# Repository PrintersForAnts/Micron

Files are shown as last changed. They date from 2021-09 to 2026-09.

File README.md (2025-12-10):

## Micron R1
Rendering of a Micron build

# [Printed Part Configurator](https://micron.wizards-enclave.net/) 
<p align="center">
  <a aria-label="Stars" href="https://github.com/PrintersForAnts/Micron/stargazers">
    </a> &nbsp;
  <a aria-label="License" href="https://github.com/PrintersForAnts/Micron/blob/master/LICENSE">
    </a> &nbsp;
  <a aria-label="Commits" href="">
    </a> &nbsp;
  <a aria-label="Discord" href="">

</p>
    
[Discord](https://discord.gg/doomcube)

[The official Micron BOM is here.](https://docs.google.com/spreadsheets/d/1caKSc-EukVpRgN67_by_hdzVPlExSRQ66j3OXlEmcCU)

If you want to purchase full kits there are 3 available (Kits are slowly updating to R1 hardware just make sure to double check the included hardware in your kit and if you have any questions reach out in the discord) 

## LDO Motors Kit 
### US Vendors
[Fabreeko](https://www.fabreeko.com/products/ldo-micron-3d-printer-kit-180mm-3d-printer-kit-with-honeybadger-upgrades)

[KB3D](https://kb-3d.com/store/shop-full-build-kits/6567-ldo-micron-r1-3d-printer-build-kit-by-hartk-6975415159954.html)

[West3d](https://west3d.com/products/ldo-micron-3d-printer-kit-micron-plus-180?_pos=1&_sid=03fbc1c81&_ss=r)

### Non US Vendors

[onetwo3d](https://www.onetwo3d.co.uk/product/ldo-micron-r1-diy-kit/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)

[Zen3d](https://shop.zen3d.eu/ldo-micronplus-r1-kit-black)

## Formbot 3d Kit 
<a href="https://www.formbot3d.com/products/voron-micron-r1-180mm-high-quality-corexy-3d-printer-kit-latest-version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" rel="nofollow">Formbot Micron+ (180x180) Kit (Affiliate Link)</a>

<a href="https://s.click.aliexpress.com/e/_DBn6Ptd" rel="sponsored">Funssor Micron (120x120) Kit (Affiliate Link)</a>

<a href="https://s.click.aliexpress.com/e/_DDDUFkF" rel="nofollow">Formbot Micron+ (180x180) Kit (Aliexpress Affiliate Link)</a>

## [R1 Change Log](https://github.com/PrintersForAnts/Micron/blob/main/R1_changeLog.md)

<details> 
   <summary>
    120x120 build
    </summary>

## Frame Extrusions
Misumi Part #  |Qty | Notes
 ----|----|----|
HFS3-1515-300 |4 | Blind holes need to be drilled
HFS3-1515-220 |10| Ends need to be tapped (M3)
HFS3-1515-205 |2 |
HFS3-1515-190 |1 |
HFS3-1515-120 |1 |

## Linear Rails
Part  | Qty | Length | Notes
-----|----|----|----|
MGN7H | 6 | 160mm | will work with V0 150mm rails if wanted, but 160mm will work as well and is recommended  
MGN9C OR MGN9H | 1 | 160mm | will work V0 150mm rails but 160 will work as well and is recommended 
</details>

<details>
    <summary>
    180x180 build
    </summary>
    
## Frame Extrusions
Misumi Part #  |Qty | Notes
 ----|----|----|
HFS3-1515-350 |4 | Blind holes need to be drilled
HFS3-1515-280 |10| Ends need to be tapped (M3)
HFS3-1515-265 |2 |
HFS3-1515-250 |1 |
HFS3-1515-180 |1 |

## Linear Rails
Part  | Qty | Length
-----|-----|-----|
MGN7H | 6 | 220mm
MGN9C OR MGN9H | 1 | 220mm 
</details>

## No Drop Nuts
There are 2 versions of this mod, 1 from [Zruncho](https://github.com/VoronDesign/VoronUsers/tree/master/printer_mods/zruncho/V0_No_Drop_Nuts) and the other from a user named [Zen3D](https://github.com/VoronDesign/VoronUsers/tree/master/printer_mods/Zen3D/V0_1515_T-nut/). Both of them have their uses. I prefer to use the Zen3D kind just for the fact that the screw can go all the way through the printed part. Zrunchos do have a much nicer fitment into the extrusions but they also dont allow the screw to go all the way through.

## Thank you
Thanks to the following people on Discord who have helped make this printer what it is today. 

- [@KyleGB](https://github.com/Jadecky) - too many additions to name them all
- @TheWarolf#1247
- @L.e.o.p.a.r.d#0990
- @deepfriedheroin#5006
- @JosAr#0517
- @sentein#3903
- @madcat#7838
- @Kyrios#5486
- @faithblinded#1491
- @zruncho#1790
- @Finn#2449
- @clee#1337
- @slidr#4412
- @gfunnymoney#3748
- Jason from LDO
- Voron Dev Team
- all the R1 beta testers
  
[You can support the Micron project on Patreon](https://www.patreon.com/user?u=27661824&fan_landing=true).

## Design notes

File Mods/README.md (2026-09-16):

# Mods

Printer mods for MICRON
Remember to update this README when uploading new mod!

## Table structure

Update the following table with the information about your mod:
- Your name
- A link to your sub-folder
- A short description of your mod

like so:
`
| Creator | [Mod title](link) | Description |`

---

| Creator | Mod title | Description |
| --- | --- | --- |
|Asica10|[Z_idler](https://github.com/Asica10/Micron/tree/main/Mods/Asica10/Z_idler) | Z idler carriage adjusted for 15mm toothed idler / Z idler body with wires cutout.
||[Crazy_Ivan_double_shear](https://github.com/Asica10/Micron/tree/main/Mods/Asica10/Crazy_Ivan_double_shear) | Crazy Ivan for double shear stepper shaft.
|LordKillZone|[3010_Side_Bedfans](https://github.com/printersforants/Micron/tree/main/Mods/LordkillZone/Side_3010_bedfans) | Bedfans mount for 3010 blower. Side  mount under bed
|BlueSandBox|[Nema_17_Z_Motor_Mount](https://github.com/printersforants/Micron/tree/main/Mods/BlueSandBox/Nema_17_Z_Motor_Mount) | Replaces the Nema14s with Nema17s
|clee|[Micron+](https://github.com/printersforants/Micron/tree/main/Mods/clee) | Micron+
|Finn2708|[Dual_MGN7_Toolhead_Carriage](https://github.com/printersforants/Micron/tree/main/Mods/Finn2708/Dual_MGN7_Toolhead_Carriage) | Dual MGN7H Toolhead Carriage 
||[Zerofilter_mounting_bracket](https://github.com/printersforants/Micron/tree/main/Mods/Finn2708/Zerofilter_mounting_bracket) | Mounting bracket for Zerofilter 
||[AB_Motor_Microfit_Connector](https://github.com/printersforants/Micron/tree/main/Mods/Finn2708/AB_Motor_Microfit_Connector) | AB Motor Microfit Connector
|Hartk|[Spinner](https://github.com/printersforants/Micron/tree/main/Mods/hartk1213/Spinner) | Spinner for Micron A/B drives.
||[LRS-150-Stacked](https://github.com/printersforants/Micron/tree/main/Mods/hartk1213/LRS-150-Stacked) | Stacked electronics for LRS-150 PSU and octopus.
||[bed_wagos](https://github.com/printersforants/Micron/tree/main/Mods/hartk1213/bed_wagos) | Bed wagos
||[plate_holder_panel_clips](https://github.com/printersforants/Micron/tree/main/Mods/hartk1213/Panel_Clip_Plate_Holder) | Plate Holder Panel Clips
||[Belt Chain](https://github.com/printersforants/Micron/tree/main/Mods/hartk1213/belt_chain) | Belt Chain 
|L.e.o.p.a.r.d|[Clips](https://github.com/printersforants/Micron/tree/main/Mods/L.e.o.p.a.r.d/Clips) | This mod contains various clips for mounting things onto 1515 and 2020 extrusion.
||[EasierZDrives](https://github.com/printersforants/Micron/tree/main/Mods/L.e.o.p.a.r.d/EasierZDrives) |  Alternate Z Drives
||[FrenzyCarriage](https://github.com/printersforants/Micron/tree/main/Mods/L.e.o.p.a.r.d/FrenzyCarriage) | Alternate Carriage for Micron and other 1515 MGN9C machines.
||[Firmware](https://github.com/printersforants/Micron/tree/main/Mods/L.e.o.p.a.r.d/Firmware) | Leopard's labeled wiring photos/examples, and mainsail config (with auto-z-calibration and sensorless X/Y)
||[HeatsetZTensioner](https://github.com/printersforants/Micron/tree/main/Mods/L.e.o.p.a.r.d/HeatsetZTensioner) | Alternate Z Idler that can utilize a heatset
||[KeyedSkirts](https://github.com/printersforants/Micron/tree/main/Mods/L.e.o.p.a.r.d/KeyedSkirts) | Keyed Skirts
||[KineKlicky](https://github.com/printersforants/Micron/tree/main/Mods/L.e.o.p.a.r.d/KineKlicky) | Kinetic-mount Klicky, useful if you're having some issues with your klicky
||[M3MicronFeetAdapter](https://github.com/printersforants/Micron/tree/main/Mods/L.e.o.p.a.r.d/M3MicronFeetAdapter) | This mod contains a hex-nut-adapter that allows you to use the standard z-drive baseplate, but install something with an M3 screw (e.g. V0 feet).
||[PiCameraMountFor1515](https://github.com/printersforants/Micron/tree/main/Mods/L.e.o.p.a.r.d/PiCameraMountFor1515) | This mod contains a mount compatible with a standard Pi camera. It articulates in various ways, and is mountable in various directions.
||[RibbitToolhead](https://github.com/printersforants/Micron/tree/main/Mods/L.e.o.p.a.r.d/RibbitToolhead) | An alternate toolhead which puts the part cooling fans on external "legs", which might improve cooling and possibly give more 'x' clearance for your gantry.
|Reiten966|[Micron Handles](https://github.com/printersforants/Micron/tree/main/Mods/Reiten966/Micron_Handles) | Handles for Micron
|TheWarolf|[Neopixel_Mount](https://github.com/printersforants/Micron/tree/main/Mods/TheWarolf/UglyNeopixelMount) | Simple Neopixel strip mount for 1515 extrusions
||[Anti_Rotation_Corners](https://github.com/printersforants/Micron/tree/main/Mods/TheWarolf/AntiRotationCorners) | Modified bed support extrusion corner pieces 
| xbst_ | [2-Piece Skirt Display Mount](./xbst_/2_Piece_Skirt_Display_Mount) | A simple insert for the middle hex of the front skirts to mount a display using the stock mount. |
|| [Drag Chain Chamber Thermistor](./xbst_/Dragchain_Thermistor) | A thermistor mount on the drag chain guide (for chamber temperature monitoring). |
|| [LED Mount](./xbst_/LED_Mount) | Top LED mount for PCB LED strips with M3 holes. |
|| [Vertical Pi](./xbst_/Vertical_Pi) | Relocates the Pi, eliminating the risk of the bottom panel shorting the pins, and makes accessing GPIO easier. Also adds a second latch for the hinge. |
|| [Simpler Electronics](./xbst_/Simpler_Electronics) | No-hinge electronics mounts for the UHP PSU, BTT Octopus & Pi. Pi Mounts to a skirt, UHP and octopus are stacked. |
|Maker Technologies|[RRF Config](https://github.com/printersforants/Micron/tree/main/Mods/Maker%20Technologies/RRF%20Firmware) | Rerprap Firmware Config for use with Duet Web Control
|gfunnymoney|[MicronPlusDinRailMount](https://github.com/PrintersForAnts/Micron/tree/main/Mods/gfunnymoney/MicronPlusDinRailMount) | Micron+ DIN rail mount
||[MicronSideSkirtKeystonePort](https://github.com/PrintersForAnts/Micron/tree/main/Mods/gfunnymoney/MicronSideSkirtKeystonePort) | Keystone side skirt Micron 120.
|CoookieTM|[OwO Chef Bolt](https://github.com/PrintersForAnts/Micron/tree/main/Mods/CoookieTM/OwO%20chef%20bolt) | Easier to print Z endstop housing
||[PIP Inner Access Z Chain](https://github.com/PrintersForAnts/Micron/tree/main/Mods/CoookieTM/PIP%20inner%20access%20z%20chain) | Print in Place Z Chain
||[Aesthetic No-Panel Clips](https://github.com/PrintersForAnts/Micron/tree/main/Mods/CoookieTM/aesthetic%20panel%20clips) | Aesthetic clips for use with NO panels
||[B Motor Ziptie Mount](https://github.com/PrintersForAnts/Micron/tree/main/Mods/CoookieTM/b%20motor%20tail%20mount) | Add-on to provide a ziptie mounting point
||[Beefed Up Side Mount Handle](https://github.com/PrintersForAnts/Micron/tree/main/Mods/CoookieTM/beefy%20handle) | Handle that is NOT compatible with panels
||[Z Motor Spinner Flags](https://github.com/PrintersForAnts/Micron/tree/main/Mods/CoookieTM/fixed%20spinner) | Rock how gangster your micron is
||[Larger Z Belt Covers](https://github.com/PrintersForAnts/Micron/tree/main/Mods/CoookieTM/larger%20z%20belt%20covers) | Covers gaps in the bottom panel
||[Spool Mount with Rollers](https://github.com/PrintersForAnts/Micron/tree/main/Mods/CoookieTM/rolling%20spool%20mount) | Reduces friction for spools
|risqy|[Micron+ 4010 Bed Fans](https://github.com/printersforants/Micron/tree/main/Mods/risqy/Micron-Plus-Bed-Fans) | Micron+ Bed Fan Mount for 2x 4010 Blower
|Shix|[MicronPlus mini12864 front skirt Mount](https://github.com/PrintersForAnts/Micron/tree/main/Mods/Shix/MicronPlus%20mini12864%20front%20skirt%20mount) | Mounting Options for the mini12864 for the front skirt of the Micron+
|G|[1515 Bed Angle Bracket (Notched)](./G/1515%20Bed%20Angle%20Bracket%20Notched) | Notched bed angle bracket for R1 Micron Filter |
||[1515 BTT SFS Mount](./G/1515%20BTT%20SFS%20Mount) | BTT Smart Filament Sensor Mount based on the bowden tube holder |
||[1515 Daygreen 5VDC Voltage Regulator Mount](./G/1515%20Daygreen%205VDC%20Regulator%20Mount) | Low profile for Micron bay mounting of the Daygreen 5VDC Voltage Regulator |
||[Bowden Tube Holder (Extended)](./G/Bowden%20Tube%20Holder%20Extended) | Extended Micron bowden tube holder to fit the R1 top panel with 3mm foam |
||[More WAGO Mounts](./G/More%20WAGO%20Mounts) | Additional wago mounts based on the micron 1515 mount for two five-port and two three-port configurations |
||[Zip Tie and PCB DIN Clip](./G/Zip%20Tie%20and%20PCB%20DIN%20Clip) | Modified PCB DIN Clip to add zip tie holes |
---

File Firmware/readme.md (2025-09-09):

# Micron Firmware Config

run this script in your terminal to download the basic Micron cfg, 

```
cd ~/printer_data/config && curl -s https://api.github.com/repos/PrintersForAnts/Micron/contents/Firmware/printer_data/config | grep download_url | cut -d '"' -f 4 | xargs -n1 curl -sOL
cd ~/printer_data/gcodes && curl -s https://api.github.com/repos/PrintersForAnts/Micron/contents/Firmware/printer_data/gcodes | grep download_url | cut -d '"' -f 4 | xargs -n1 curl -sOL
```

make sure to go through the entire cfg and uncomment the sections required 

* Build Size (120 or 180) 
* MCU
* Toolhead MCU
* Probe

This will download he default config as well as a sample gcode for printing a test cube

to initiate the test cube print, run the macro 

`PRINT_TEST_CUBE` 
then your webui will prompt you to choose which filament type you are using for the test print 


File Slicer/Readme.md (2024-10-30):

Slicer Profiles, Bed Models, Bed textures can be found here

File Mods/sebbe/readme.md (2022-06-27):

<h1> Hardware for all my voron projects utilize standard m3 heatset inserts & various lengths of m3 screws </h1>

Feel free to mod / change the parts as you like :-)

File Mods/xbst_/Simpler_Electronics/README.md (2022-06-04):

# Simpler Electronics
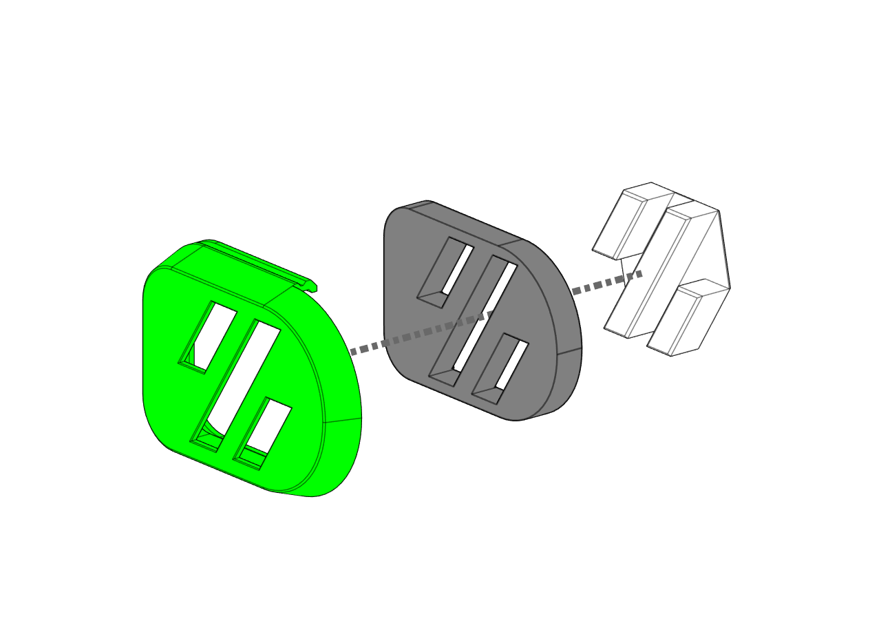
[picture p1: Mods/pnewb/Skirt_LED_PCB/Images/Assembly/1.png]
Example

<br>
I wasn't a fan of the hinged electronics (below), so I created this. Less files to print, less screws and inserts needed, more accessible Pi, and no hinge.
<br>
The PSU is VHB taped or screwed to the deck panel, the Octopus mount is VHB taped on the PSU. Pi mounts to a side skirt.
<br>
There are 2 versions of the Pi skirt, with M2 self-tapper screws or with M2.5 inserts. I like using inserts where possible, and M2.5 is the correct screw size for a Raspberry Pi, so this is what I use. The M2.5 inserts I used can be found on [Aliexpress](https://s.click.aliexpress.com/e/_9gw57l), size M2.5 X D4.2 X L3.6.
<br>

### Why I didn't like the hinge?
1. Wire management was difficult. Managing wires to not go under the PSU was difficult. Wires under the PSU means you con't lock the latch.
2. It was unnecessary. Hinge doesn't make accesing the components easier. The PSU is still screwed under the Octopus, blocking the DC side.
3. Pi mounting location wasn't ideal. You needed to remove screws to access the Pi, and the bottom side was facing the bottom panel, increasing shorting risk (if bottom panel is ACM). I designed [a mod](../Vertical_Pi) to fix this if you still want the hinge.

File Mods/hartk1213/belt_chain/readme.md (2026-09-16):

## Belt Chain
printed alternative for the Z chain that uses a length of gt2 belt down the center of it 




to secure the belt to the chain ends , a short piece of filament is pressed into the printed part between the teeth of the belt


then you can thread each link down onto the belt one at a time 


then secure the other end the same way you did the first end 

this works with stock [Micron 2 hole chain mounts](https://github.com/PrintersForAnts/Micron/tree/main/STLs/Z_Chain/2_hole_chain)

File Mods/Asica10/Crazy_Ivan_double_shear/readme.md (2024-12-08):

# Crazy Ivan with double shear
In Crazy Ivan mod one stepper is mounted upside down. The main advantage of this solution is that you can use a standard stepper with a 22 mm shaft, which is supported by a bearing over the entire thickness of the bearing.
Mod required 2pcs of F695 flanged bearing.

Note: for this mod you need to print 2x B stepper mod from main repo ( A stepper mod is not used).









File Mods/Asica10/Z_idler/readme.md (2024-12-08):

# Z idler carriage adjusted for 15mm toothed idler 
For idler from Mellow 3D.
You can choose between standard version - screw as an axis



or pin_mod version OD3 x 19mm





# Z idler body with wires cutout

For easier wire routing ( e.g LED or camera)







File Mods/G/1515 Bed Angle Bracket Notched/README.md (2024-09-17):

# 1515 Bed Angle Bracket (Notched)

This is a modifed bed angle bracket to allow the use of the Micron R1 filter with the original shorter bed mount extrusions and bracket. 

Mirror the part in the slicer to print the opposite side. 

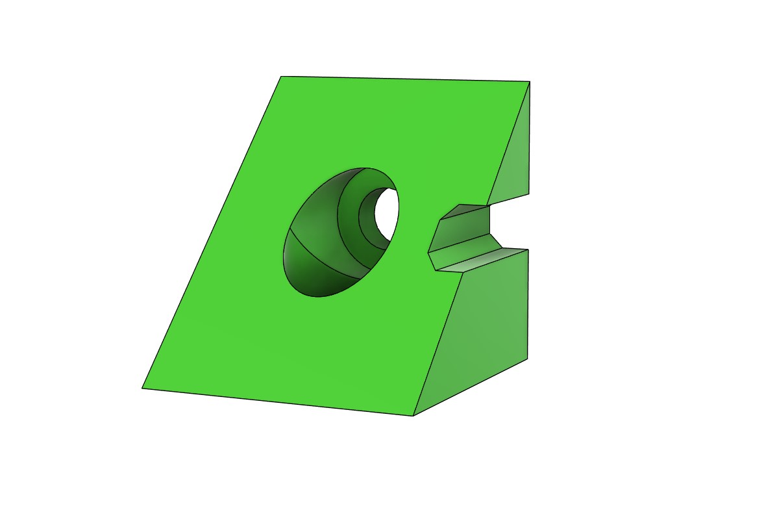
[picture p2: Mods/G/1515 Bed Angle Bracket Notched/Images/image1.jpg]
CAD image


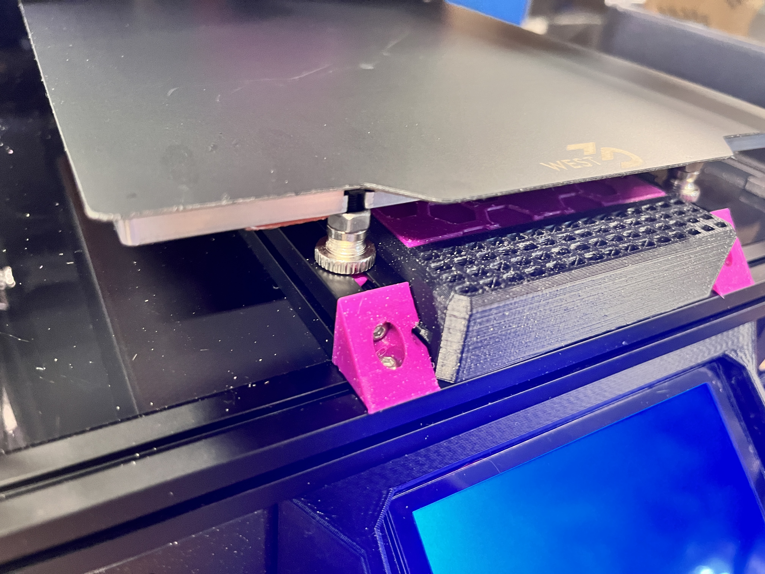
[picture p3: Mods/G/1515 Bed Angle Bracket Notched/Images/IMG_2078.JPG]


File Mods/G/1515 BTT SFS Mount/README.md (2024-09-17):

# 1515 BTT SFS Mount

This is a mount based off of the Micron Bowden Tube Holder and is intended to be used in place of one. Install an M3 heatset insert in the printed bcakplate and replace the SFS backplate with the printed part using using the same screws. The SFS is secured to the bracket with a 20mm long screw. 

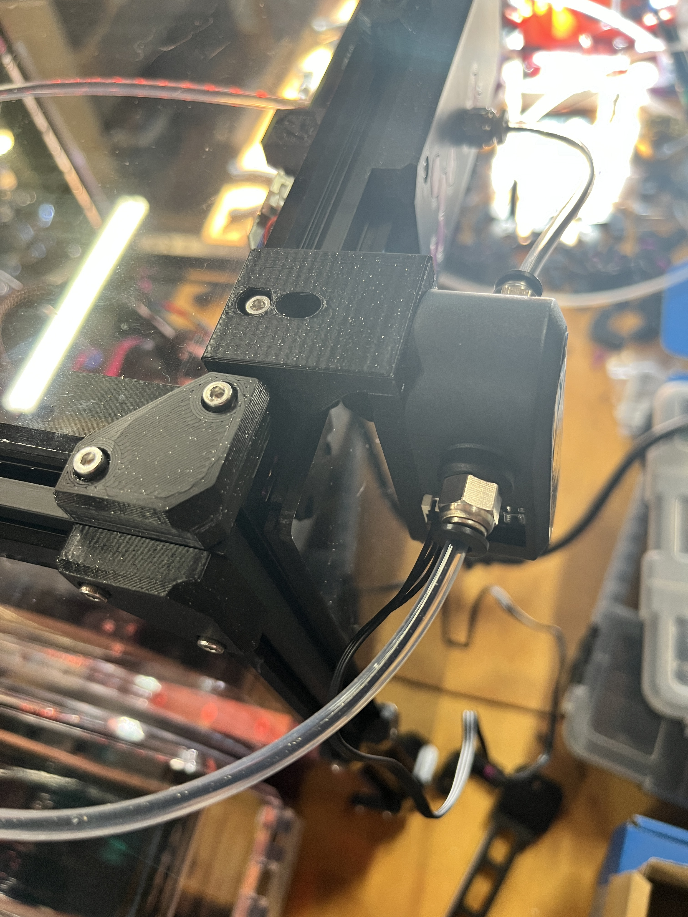
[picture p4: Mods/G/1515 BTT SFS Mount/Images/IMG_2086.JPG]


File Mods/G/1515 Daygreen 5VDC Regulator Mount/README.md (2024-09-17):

# 1515 Daygreen 5VDC Regulator Mount

This is a mount based off of the 1515 WAGO mount to secure a Daygreen 5VDC Voltage Regulator. Four heatset inserts are used in the mount to fasten the regulator. 

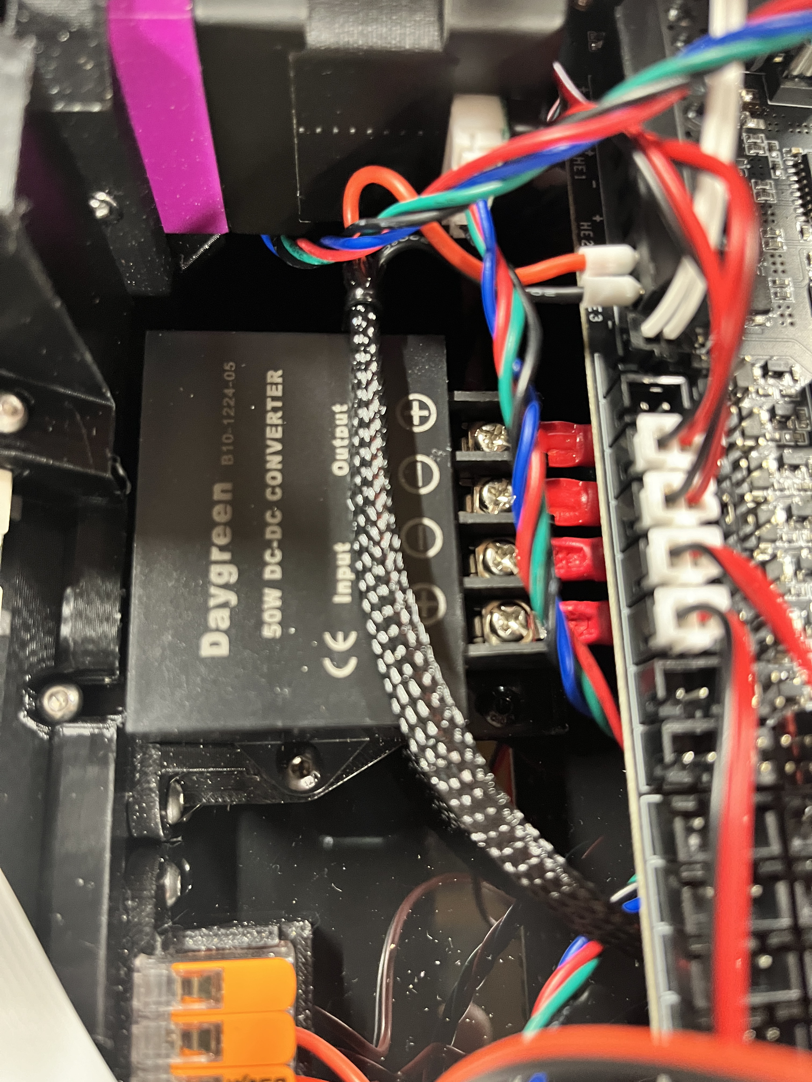
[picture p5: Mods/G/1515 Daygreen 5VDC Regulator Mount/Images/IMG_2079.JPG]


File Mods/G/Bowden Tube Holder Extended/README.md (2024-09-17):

# Bowden Tube Holder Extended

This is a modified Bowden Tube Holder to fit the R1 panels with 3mm foam underneath.

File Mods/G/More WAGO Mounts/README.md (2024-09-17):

# More WAGO Mounts

These are modified from the Micron 1515 WAGO Mount for two three-port and two five-port WAGOs.

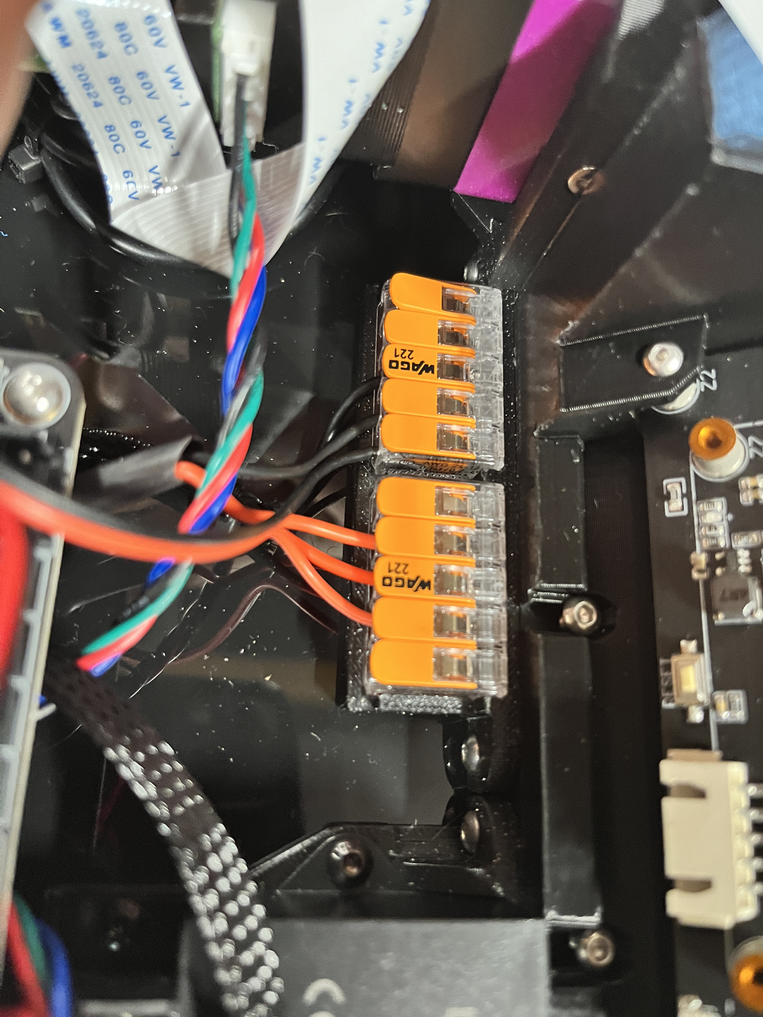
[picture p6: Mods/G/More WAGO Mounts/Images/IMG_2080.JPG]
five-port


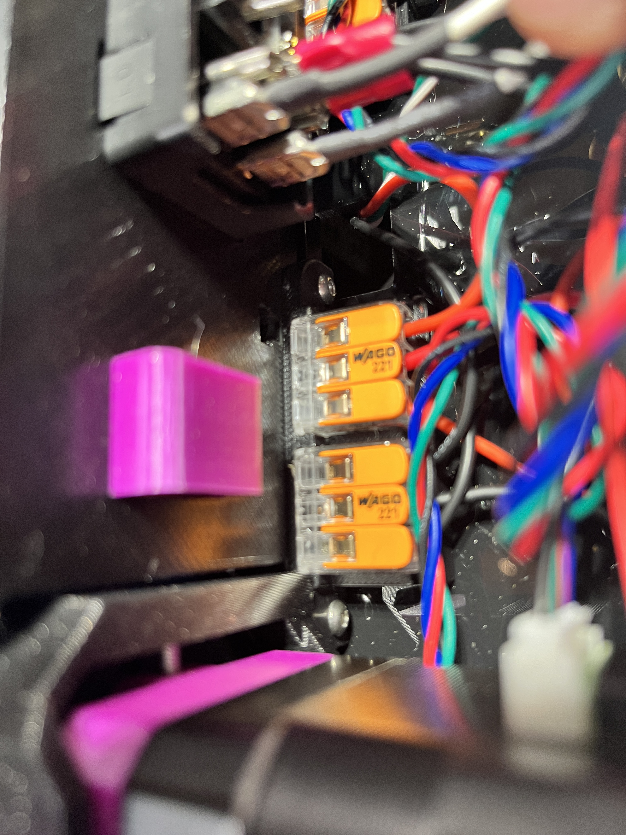
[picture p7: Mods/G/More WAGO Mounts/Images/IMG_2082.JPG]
two-port


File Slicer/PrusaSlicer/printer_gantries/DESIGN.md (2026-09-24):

# Design notes — Micron / Anthead sequential-print geometry

> **Derived with [Claude](https://claude.com/claude-code).** The slice semantics were read out
> of the PrusaSlicer source, the envelope was measured from the toolhead mesh, and both
> verification passes below were run programmatically. Reviewed by a human before submission,
> but treat the numbers as machine-derived and check them against your own hardware.

How the envelope in `micron_anthead_gantry.json` was derived from the toolhead mesh, and why it
is shaped the way it is. Installation is covered in [README.md](README.md).

## How PrusaSlicer consumes the file

`ArrangeHelper.cpp :: get_printer_geometry()` matches `printer_notes_regex` against the printer
profile's Notes, parses the slice list, and hands it to `libseqarrange`. For every height *h* in
the file it takes the convex hull of everything in the object **above** *h*:

```cpp
Polygon pgn = its_convex_hull_2d_above(raw_mesh.its, matrix, height - offset.z());
```

and pairs it with that slice's polygons. Consequences worth knowing:

- Each slice is an independent constraint — "no object material above *h* may fall inside these
  polygons" — so a polygon at height *h* behaves like an **infinite column from h upward**. It
  only *needs* to enclose the toolhead between *h* and the next height, but may be larger.
- Heights are measured from the bed, which coincides with "above the nozzle" in the worst case
  (nozzle down on layer 1). That is why the STL is authored with the nozzle tip at z = 0.
- Coverage only has to hold in aggregate. The `h = 33` entry contains *only* the rail; the body
  of the head above 33 mm is already handled by the `h = 3` box, because the hull above 3 mm is
  a superset of the hull above 33 mm.

### `convex` vs `box`

`convex` is a true Minkowski sum of the two outlines. `box` runs through
`extend_PolygonBoxUnreachableZone()`, which takes the **axis-aligned bounding box of both** and
adds the extents. That is why the rail is written as ±100 rather than its true ±125: on a
160 mm bed, an object's AABB offset by 100 mm already spans the whole plate, so any half-extent
past the plate is equivalent. It is a cheap total constraint, not a measurement.

### Why the polygons are point-reflected

The configuration-space obstacle for a rigid tool *T* against an object *O* is *O* ⊕ (−*T*).
`libseqarrange` sums the stored polygon directly, with no negation step anywhere in the
pipeline:

```cpp
// seq_preprocess.cpp — extend_PolygonConvexUnreachableZone()
ClipperLib::MinkowskiSum(extruder_polygons[i].points, polygon.points, paths, true);
```

so the file has to hold **−T** already. For a shape reflected through the origin that is a 180°
rotation about Z:

```
x_json = -x_stl     y_json = -y_stl     z_json = z_stl
```

## Re-zeroing the mesh

The source mesh is not authored on the nozzle — the tip sits at (−0.089, −12.792, −53.688),
with X = 0 on the gantry centreline and Z = 0 somewhere in the carriage. Everything here is
expressed after translating that point to the origin, which puts the model at X ±125,
Y −26.3…54.3, Z 0…129.

This matters for display as well as measurement. PrusaSlicer positions a custom gantry marker
with a pure translation:

```cpp
: Geometry::translation_transform(m_world_position.cast<double>());
```

No rotation, no offset — the flip and `m_model_z_offset` only apply to the generic fallback
cone. The model origin *is* the nozzle, so the un-re-zeroed mesh renders 53.7 mm low.

The shipped STL is that translation applied, decimated to 70 k triangles (3.5 MB, down from
51 MB ASCII). Bounds should read roughly `[[-124.9, -26.4, -0.015], [125.1, 54.3, 128.95]]`.

The X rail landing 21.4–42.9 mm behind the nozzle at 33–48 mm up confirms **+Y = rear**, the
same convention the Prusa files use, so no extra rotation is needed beyond the reflection.

## Slice-by-slice

| h | type | polygon (printer frame) | covers | measured mesh |
| --- | --- | --- | --- | --- |
| 0 | convex | X −3.4…3.3, Y −3.6…3.4 | nozzle cone — the only thing below 1 mm | X −1.75…1.5, Y −1.75…1.5 |
| 1 | convex | legs X −26.2…−4.7 and 4.8…26.3 (Y −26.8…34.2); block ±8.5 | duct shrouds, heater block and sock | legs Y −24.8…32.2, block ±6.5 |
| 3 | convex | X −29.7…29.8, Y −28.3…47.7 | full toolhead body, carries to z = 33 and under the rail to 49 | X −27.8…27.5, Y −26.5…45.5 |
| 33 | box | X ±100, Y 19.4…45.2 | MGN rail + 1515 X extrusion, spans the machine | Y 21.4…42.9, z 33…48 |
| 49 | convex | X −30.9…35.3 (Y −28.3…21.4); X −30.4…27.8 (Y 43.2…56.4) | extruder deck, motor and blower above the rail | X −28.8…33, Y −26.5…54.3 |

Notes on the individual slices:

- **The shrouds come down to 1.5 mm above the nozzle tip**, much tighter than any Prusa head.
  That is why slice 0 is only ±3.4 and slice 1 starts at 1 mm rather than the 2–3 mm Prusa
  uses. Below 1 mm the nozzle cone is genuinely the only thing there.
- **Slice 1 is three rectangles.** The duct legs leave a 9.5 mm slot at the centreline occupied
  only by the heater block. Collapsing to a single rectangle
  `-26.3,-34.2;26.3,-34.2;26.3,26.8;-26.3,26.8` costs about 9 % more forbidden area and is
  easier to hand-edit — either is correct.
- **Slice 49 is split for a reason.** The middle strip of the upper assembly falls inside slice
  33, which already blocks that Y band across the whole plate for anything taller than 33 mm.
  Splitting around it is free.
- **Being CoreXY helps.** The X extrusion translates in Y with the toolhead, so it is rigid
  relative to the nozzle and maps cleanly onto slice 33. The Y rails and frame sit outside the
  plate, and a tall model hits the underside of the gantry or the sides of the head long before
  it clears anything, so no additional constraint is needed above the head.

Envelope carries a **2 mm** margin over the measured geometry, mid-range for what Prusa ships
(their MINI file runs 1–3 mm).

## Verification

Two independent passes:

1. Every band rasterised at 0.25 mm and tested against the union of all slices at or below its
   start height.
2. 383 648 points sampled uniformly over the mesh surface, point-reflected, each tested for
   containment in the polygons applicable at its own Z.

| band | slices in force | mesh footprint mm² | uncovered mm² |
| --- | --- | --- | --- |
| z ∈ [0, 1) | 0 | 6.1 | 0.0 |
| z ∈ [1, 3) | 0, 1 | 895.7 | 0.0 |
| z ∈ [3, 33) | 0–3 | 3228.3 | 0.0 |
| z ∈ [33, 49) | 0–33 | 6273.3 | 0.0 |
| z ∈ [49, 129) | all | 4221.1 | 0.0 |

Surface sampling: 383 648 points inside ±100 mm, zero uncovered.

## Regenerating

`gen_geom.py` rebuilds the entry from a mesh:

```bash
python3 gen_geom.py Micron_Anthead_Gantry.stl \
    --bed 160x160 --margin 2 \
    --heights 0,1,3,49 --box-heights 33 \
    --regex '.*PRINTER_MODEL_MICRON.*' \
    --gantry-file micron_anthead_gantry.stl
```

It auto-detects the nozzle tip as the lowest isolated feature (override with `--nozzle X,Y,Z`),
gives each convex slice ownership of the band from its own height to the next, pulls
machine-spanning members out into `box` slices, and prints a per-band coverage audit to stderr.
If a band leaks it says so and where — add a height there or raise the margin.

Requires `trimesh numpy scipy pillow`.

## Gotcha for anyone editing the JSON by hand

**Do not put two slices at the same height.** PrusaSlicer stores them in a
`std::map<coord_t, std::vector<Polygon>>` and uses `insert()`, which does not overwrite — a
second entry at the same height is silently dropped. The shipped file already does this: the
CoreOne and CoreOne L entries each declare two slices at `h = 23`, and the second never reaches
the solver. Put multiple shapes in one slice's `polygons` array instead.

## Relationship to the Radius / Height settings

While the entry matches, `extruder_clearance_radius` and `extruder_clearance_height` are unused
for collision detection — `get_printer_geometry()` only builds the cylinder fallback when the
slice list comes back empty (Notes blank, JSON unparseable, or no regex match).

Two things still apply:

- Keep both **non-zero**. `PrintConfigDef::validate()` rejects `<= 0`.
- The radius feeds `min_object_distance()`, which sets the lower bound of the Arrange tool's
  "distance from objects" range when Complete individual objects is on. Inflating it costs
  plate density.

If you want the fallback to be honest rather than decorative: `height = 33` (nozzle tip to the
underside of the X rail) and `radius = 55` — the fallback is a *square* of half-side `r` centred
on the nozzle, and the head reaches Y +54.3 at the rear. That 55 mm then becomes the arrange
spacing floor, which is punishing on a 160 mm bed, so it is a real trade-off.

## Source references

PrusaSlicer master:

- `src/libslic3r/ArrangeHelper.cpp`
- `src/libseqarrange/src/seq_preprocess.cpp`
- `src/libseqarrange/include/libseqarrange/seq_interface.hpp`
- `src/slic3r/GUI/GCodeViewer.cpp`, `src/slic3r/GUI/GLCanvas3D.cpp`

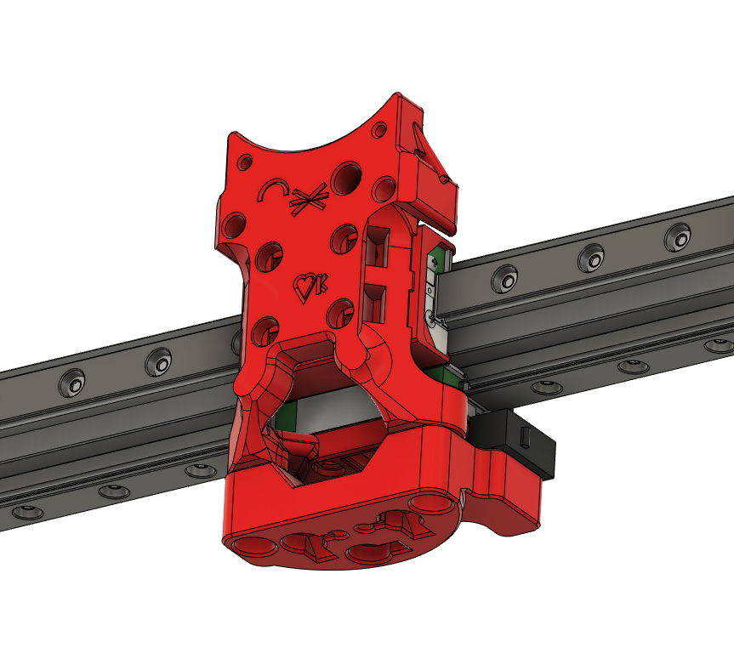
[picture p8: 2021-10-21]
Mods/Finn2708/Dual_MGN7_Toolhead_Carriage/Images/Overview.PNG

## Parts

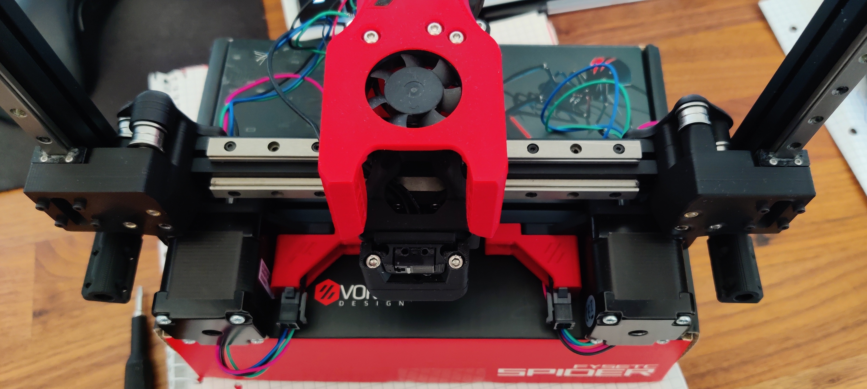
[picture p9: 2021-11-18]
Mods/Finn2708/AB_Motor_Microfit_Connector/Images/printed_parts.jpg

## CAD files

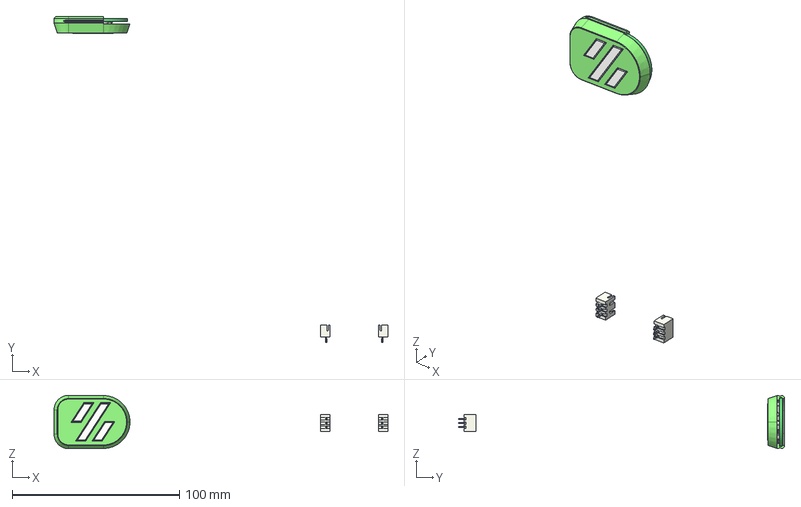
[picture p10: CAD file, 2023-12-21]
Mods/pnewb/Skirt_LED_PCB/CAD/Skirt_LED_Assembly.step
199.5 x 194.8 x 31.9 mm
Disco Skirt PCB (1)
Skirt_Logo_Cover
LightBlocker
Diffuser

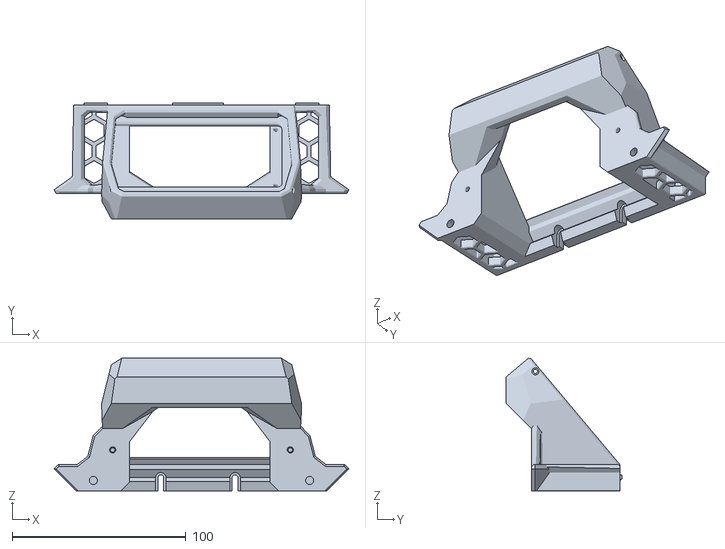
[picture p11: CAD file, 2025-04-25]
STLs/Skirts/Displays/TFT35/main_housing.stl
169.9 x 66.6 x 76.4

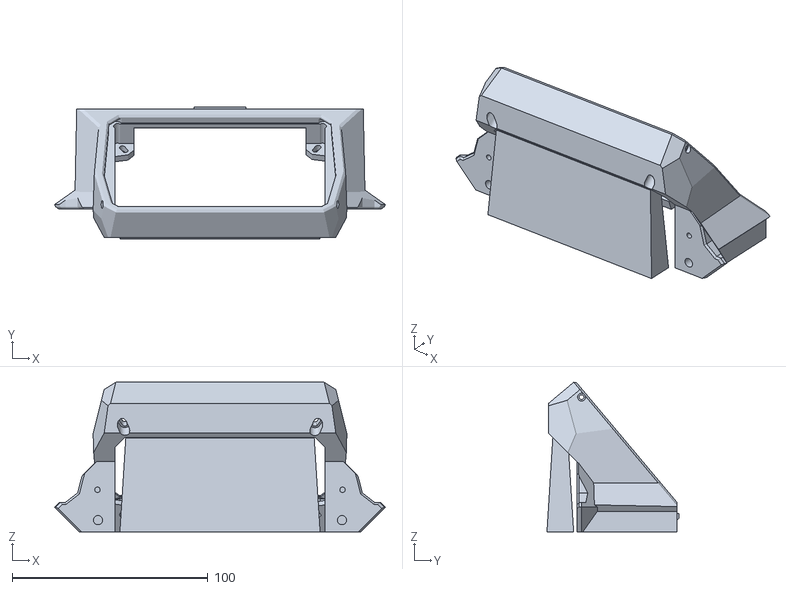
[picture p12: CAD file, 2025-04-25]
STLs/Skirts/Displays/Waveshare43_BTT43/waveshare_btt43_main_housing_x1.stl
169.0 x 67.5 x 76.4

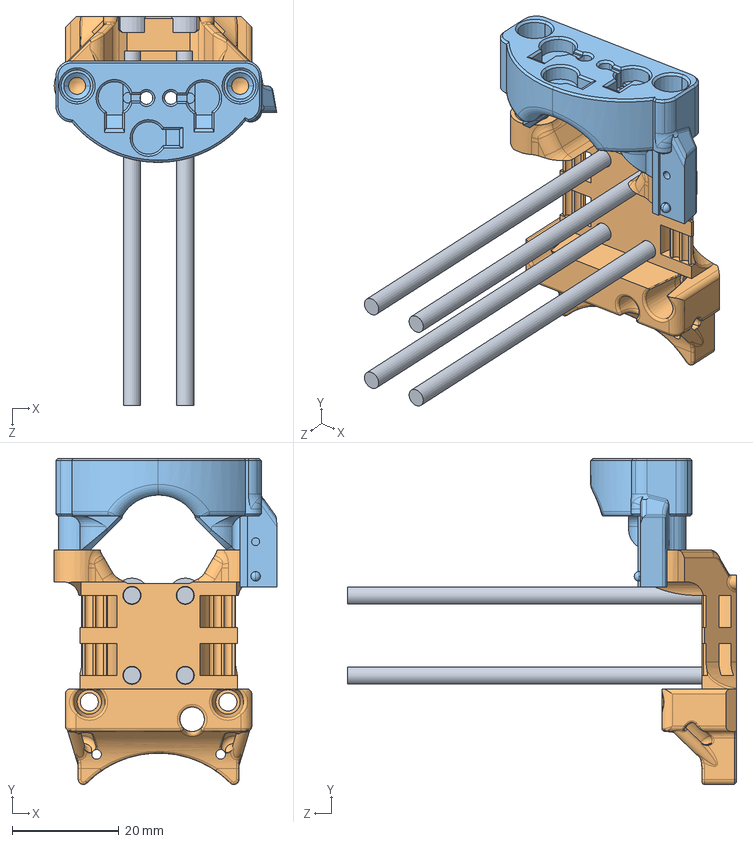
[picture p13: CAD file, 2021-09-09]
CAD/Cad Files/carriage/shorter_micron_carriage.SLDASM
41.8 x 61.2 x 73.0 mm
M3 SHCS Bridge Cutter v6.step x 4
shorter_micron_carriage2
airflow_modded_bottom_micron_toolhead^shorter_micron_carriage

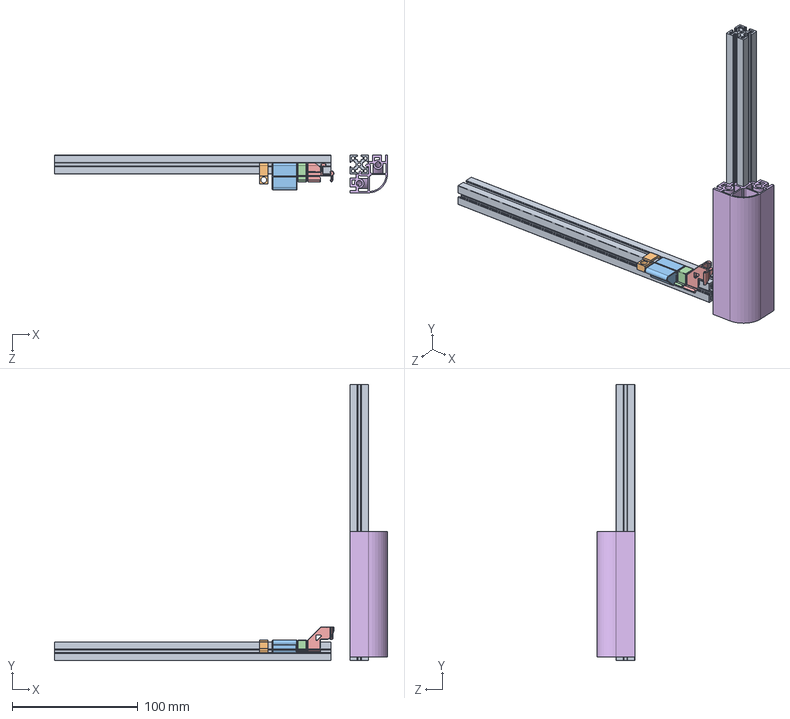
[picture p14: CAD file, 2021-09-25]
Mods/L.e.o.p.a.r.d/Clips/CAD/clips.SLDASM
265.0 x 220.0 x 30.0 mm
1515_220mm (4)^clips x 2
panel_clip^clips
corner panel_clip^clips
fake_3030_l_shape_with_radius^clips

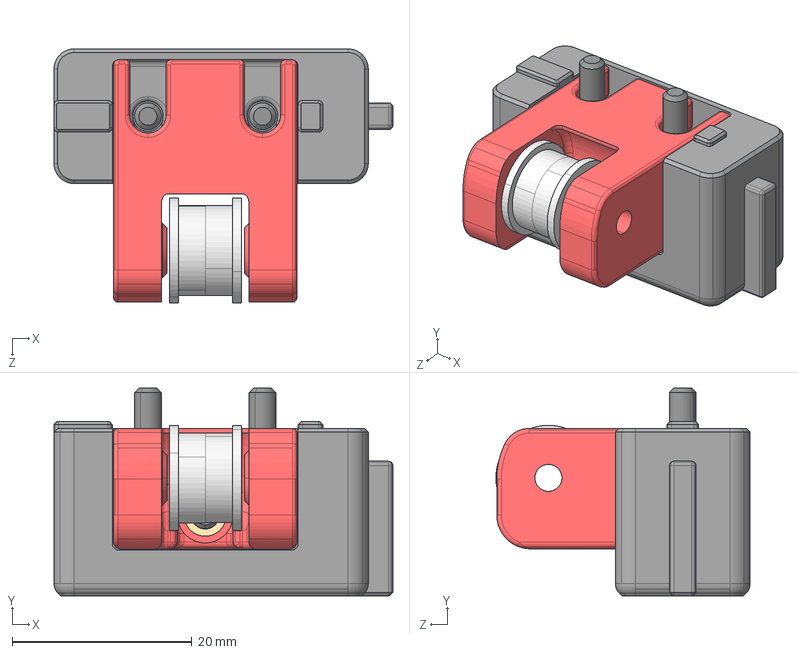
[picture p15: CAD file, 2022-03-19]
Mods/L.e.o.p.a.r.d/HeatsetZTensioner/CAD/safer_z_idlers_asmb.STEP
37.7 x 23.2 x 28.3 mm
safer_z_idler
z_tensioner_heatset_pinned
Copy of M3 Threaded Insert (6)^safer_z_idlers
Copy of f623-rs (2) (2)^safer_z_idlers
Copy (2) of f623-rs (2) (2)^safer_z_idlers
Copy of M3x12 BHCS (1) (1)^safer_z_idlers
Copy of M3x20 BHCS (2) (1) (1)^safer_z_idlers
Copy (2) of M3x20 BHCS (2) (1) (1)^safer_z_idlers

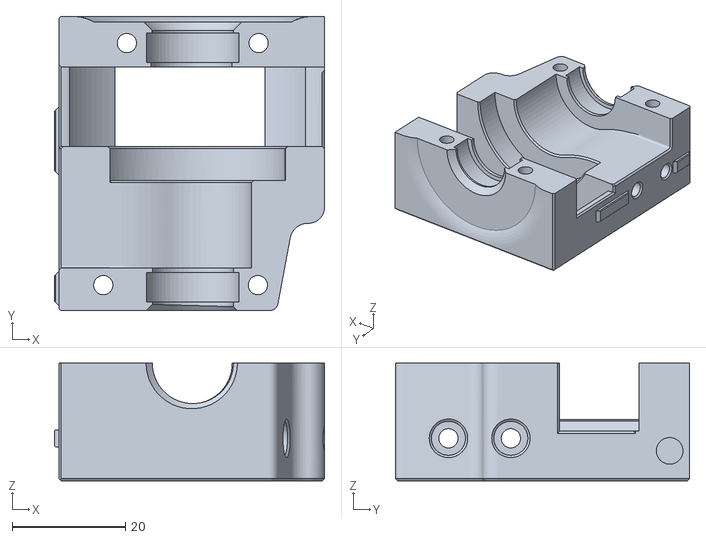
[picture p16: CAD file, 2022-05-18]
Mods/sebbe/powge60t-zdrives/stls/Z-Main_x2.stl
47.6 x 51.9 x 20.8

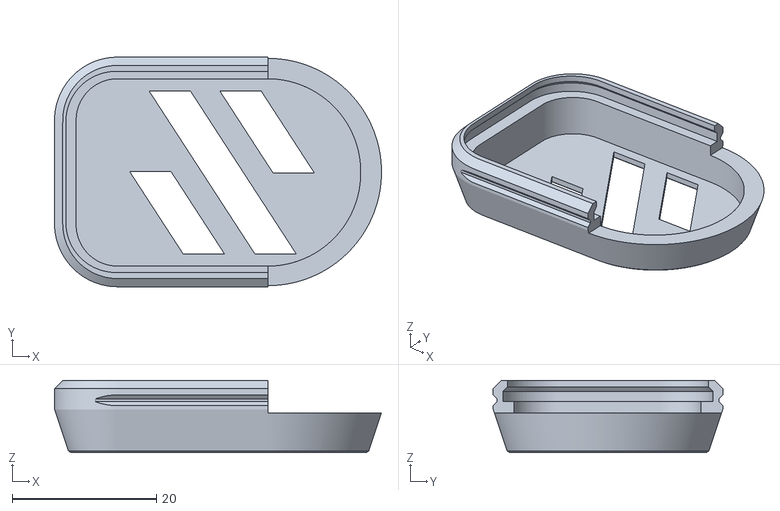
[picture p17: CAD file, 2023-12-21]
Mods/pnewb/Skirt_LED_PCB/STLs/[a]_main_body.stl
45.4 x 31.9 x 10.0

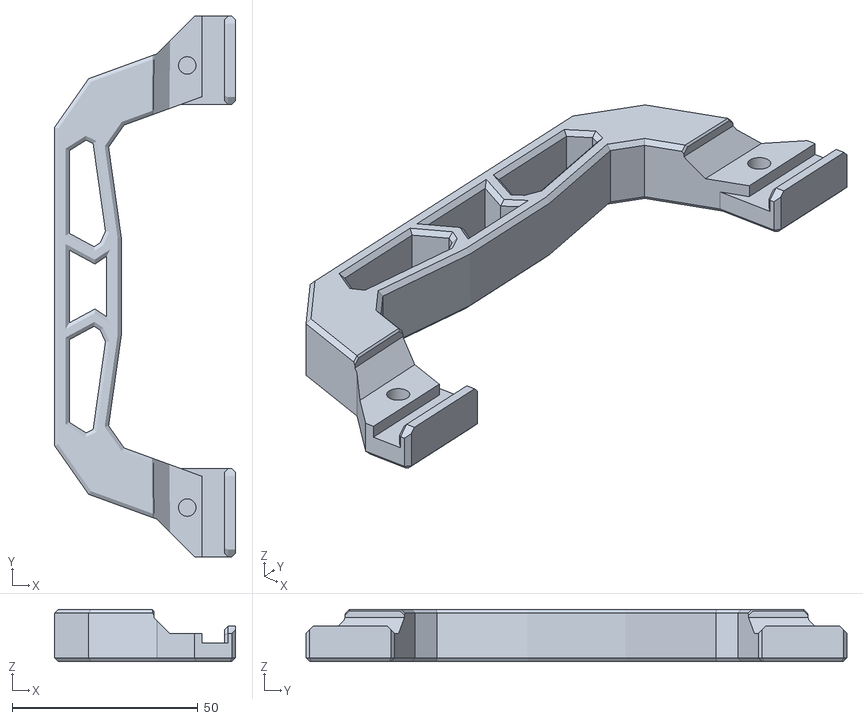
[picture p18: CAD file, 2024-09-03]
STLs/MISC/main_handle_x2.stl
48.8 x 145.7 x 14.1

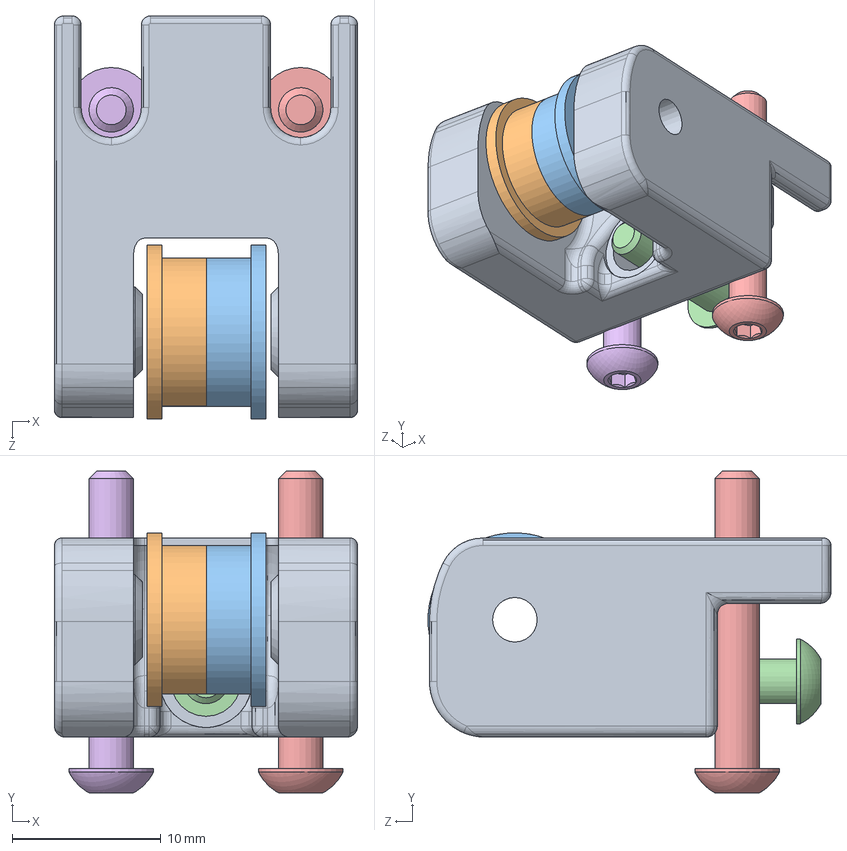
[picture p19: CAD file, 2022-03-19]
Mods/L.e.o.p.a.r.d/HeatsetZTensioner/CAD/safer_z_idlers.SLDASM
20.4 x 21.6 x 27.1 mm
z_tensioner_heatset
Copy of f623-rs (2) (2)^safer_z_idlers
Copy (2) of f623-rs (2) (2)^safer_z_idlers
Copy of M3x12 BHCS (1) (1)^safer_z_idlers
Copy of M3x20 BHCS (2) (1) (1)^safer_z_idlers
Copy (2) of M3x20 BHCS (2) (1) (1)^safer_z_idlers

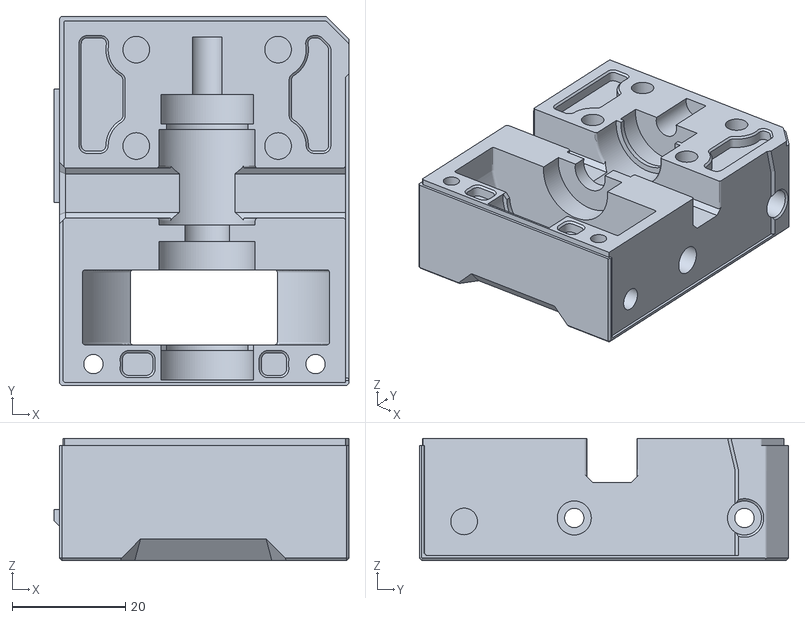
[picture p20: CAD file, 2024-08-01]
STLs/Z_Drive/main_body_a_x2.stl
52.0 x 65.1 x 21.5

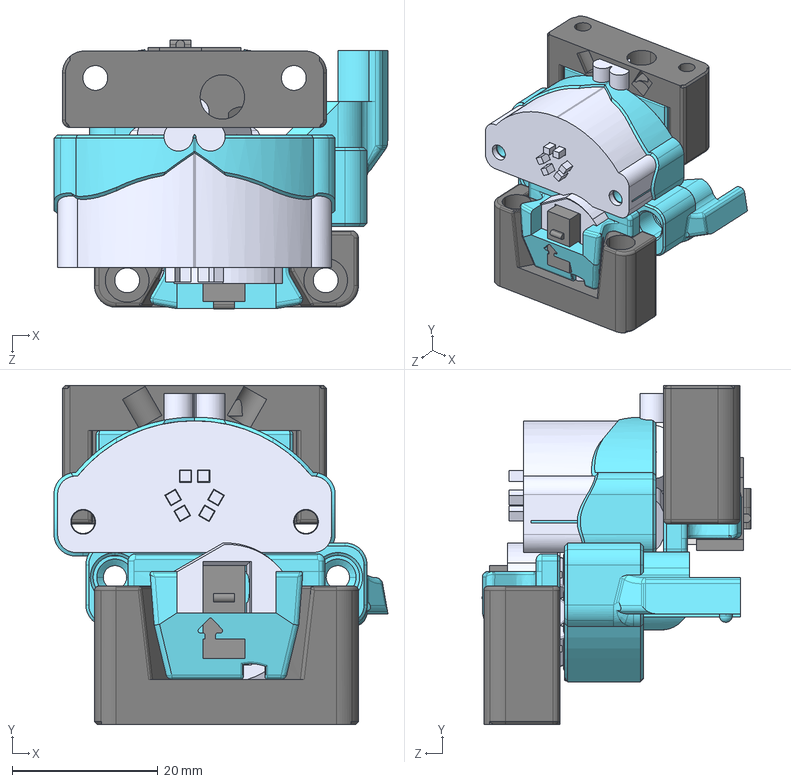
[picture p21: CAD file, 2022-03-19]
Mods/L.e.o.p.a.r.d/KineKlicky/CAD/kineklicky_assembly.step
45.9 x 46.5 x 36.9 mm
kineklicky_probe_body^kineklicky
4x4.6 neodymium magnet^kineklicky x 9
Omron_D2F^kineklicky x 4
kineklicky-switch_side
kineklicky-mount_side
kineklicky_micron_mount^kineklicky
Copy of Probe v0.2-74^kineklicky
Copy of Probe Dock v0.2-75^kineklicky x 2
kineklicky_probe^kineklicky
kineklicky_negative^kineklicky
probe^kineklicky
single kineklicky_negative^kineklicky x 3
Copy of Copy of kineklicky_micron_mount^kineklicky
mount mag insertion support^kineklicky

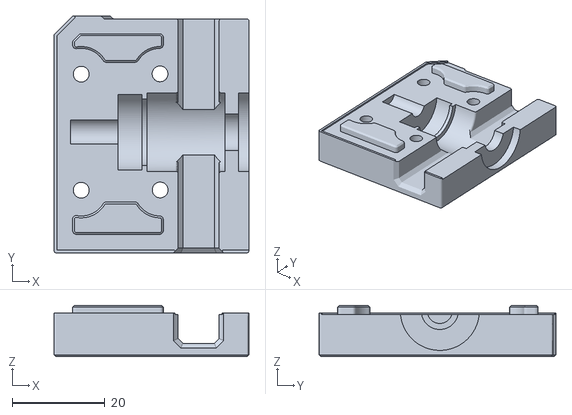
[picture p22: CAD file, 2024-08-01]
STLs/Z_Drive/[a]_shaft_assembly_cover_b_x2.stl
42.0 x 51.0 x 11.0

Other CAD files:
Mods/sebbe/powge60t-zdrives/step/Z-Main-Mirror.step
Mods/sebbe/powge60t-zdrives/stls/Z-Main-Mirror_x2.stl
Mods/sebbe/powge60t-zdrives/step/Z-Main.step
STLs/Z_Drive/[a]_shaft_assembly_cover_a_x2.stl
STLs/Z_Drive/main_body_b_x2.stl
CAD/Cad Files/MIC6 Plate 120x120mm.step
CAD/Cad Files/carriage/airflow_modded_bottom_micron_toolhead^shorter_micron_carriage.STEP
CAD/Cad Files/carriage/shorter_micron_carriage2.SLDPRT
CAD/Cad Files/carriage/shorter_micron_carriage2.STEP
CAD/Cad Files/carriage/shorter_micron_carriage_for_m3x8mm.SLDPRT
CAD/Cad Files/carriage/shorter_micron_carriage_for_m3x8mm.STEP
CAD/Cad Files/electronics_mounting/flat/octopus_spider_and_pi_mount.SLDPRT
CAD/Cad Files/electronics_mounting/flat/uhp-200 mount mirrored.STEP
CAD/Cad Files/electronics_mounting/flat/uhp-200 mount.SLDPRT
CAD/Cad Files/electronics_mounting/flat/uhp-200 mount.STEP
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

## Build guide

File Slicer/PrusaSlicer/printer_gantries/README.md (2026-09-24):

# Sequential-print geometry for the Micron (Anthead toolhead)

Adds collision-aware sequential printing ("Complete individual objects") for a Micron running
the Anthead toolhead, so PrusaSlicer uses a real model of the head instead of the generic
nozzle-cylinder approximation.

Bed 160 × 160. See [DESIGN.md](DESIGN.md) for how the envelope was derived and verified.

## Install

Both files go in `resources/data/printer_gantries/`.

| File | Action |
| --- | --- |
| `micron_anthead_gantry.stl` | copy into the directory |
| `micron_anthead_gantry.json` | **prepend** its object to the `printers` array in `geometries.json` |

PrusaSlicer walks `printers` in order and stops at the first `printer_notes_regex` that matches,
so the entry must go **first** in the array to take precedence.

## ⚠️ Required: printer profile notes

**The printer profile must contain `PRINTER_MODEL_MICRON` in Printer Settings → Notes.**

Nothing else selects this geometry. Matching is done purely against that field — profile name,
printer model and vendor are all ignored. Other text in Notes is fine; the marker just has to
appear somewhere in it.

Then enable **Print Settings → Output options → Complete individual objects**.

## Checking that it took

Look at the toolhead marker on the plater:

> If the plater is drawing your Anthead, the geometry entry matched and the fallback is
> dormant. Generic cone = you've lost the match and PrusaSlicer falls back to sequential
> printing limits; radius and height.

The marker and the collision model are resolved through the same lookup, so the picture is a
reliable tell. The fallback is silent — no warning, no log entry — so this is worth a glance
after any edit to Printer Notes.

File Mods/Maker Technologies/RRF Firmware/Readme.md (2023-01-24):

Use this config as a base to develop RRF for your machine. This was made using pRINTERnOODLE's config (https://github.com/pRINTERnOODLE/RRF-klicky-probe-voron-2.4) and has integrated z calibration (https://github.com/pRINTERnOODLE/Auto-Z-calibration-for-RRF-3.3-or-later-and-Klicky-Probe). Big thank you to them for doing most of the legwork. I did make some siginificant changes, mostly in the name of simplification and consolidation. There are still some unused macros that I will get around to cleaning up eventually, but in the meantime they have just been commented out. The hardware used for this config was the BTT Octopus pro 429, TMC 2209s, BTT wifi card and a Paneldue i7.

I used the AC heated bed mod, which is why the bed heater pin looks a bit weird. It uses a 5V relay and I used the PS_ON pin to control the bed instead of allocating a fan port. Do note that this pin is on by default which will start heating your bed if the pin is not defined. This config will work fine for the DC bed as well, just move the bed mosfet pin to the 24v rail.

Pay attention to the order of the motors in config.g! I skipped over port 04. This was because I could not get the original config to work with the correct z motor numbering. If you can figure this out please let me know! Until then, config.g tells you how to wire the z motors.

I have also defined macros for start and end gcode, which can be called up using M98 P"/macros/start.g" and M98 P"/macros/end.g" respectivly. 

My Micron (V2.4085), was built in between models, so there are a few things that are probabably different for you. It is a good idea to go through both the config and macros to make sure everything macthes up.

More information on how to get RRF on your board (and compatible boards themselves) can be found here: https://teamgloomy.github.io/

I have been using this config for quite a while with great success. I do plan on still implimenting a few things in the distant future. Specfically accelerometer support. RRF can be quite an uphill battle with these things though, so please be patient. 

-Dom Dell Optiplex 7000#0675

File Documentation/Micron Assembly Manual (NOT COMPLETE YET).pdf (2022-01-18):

# MICRON

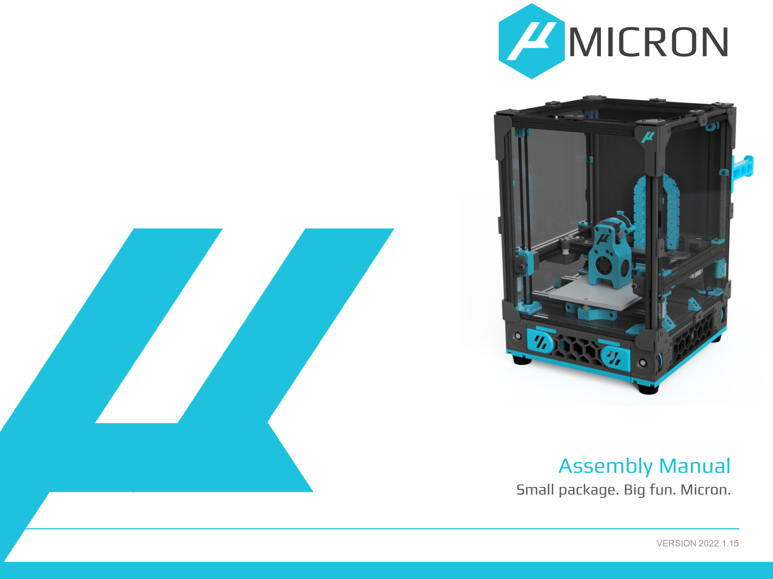
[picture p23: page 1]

# Assembly Manual

VERSION 2022.1.15

Small package. Big fun. Micron.

MICRON

Introduction | 03
Frame | 06
TABLE OF CONTENTS | MICRON

2

INTRODUCTION

3

ACKNOWLEDGEMENTS | MICRON

This printer wouldn’t have happened if it were not for all the hard work from the following users on the Voron Discord and Doom Discord

- TheWarolf
- L.e.o.p.a.r.d
- deepfriedheroin
- faithblinded
- zruncho
- Finn
- DocSparky
- gfunnymoney

4

INTRODUCTION

STL FILE KEY

PRINT GUIDELINES

The STL files naming convention is the same as for VORON designs, namely :

The print guidelines are also the same as for VORON designs, namely :

PRIMARY COLOR

Example z_drive_main_a_x2.stl These files will have nothing at the start of the filename.

ACCENT COLOR

Example [a]_z_motor_mount_a_x2.stl These files will have ‘’[a]’’ to the front to mention that they are intended to be printed with an accent color.

QUANTITY REQUIRED

Example [a]_z_motor_mount_a_x2.stl If a file ends with ‘’_x#’’, that is telling you the quantity of that part required to build this system..

FDM MATERIAL

As with the standard Voron Design printers, Its is recommended to print these parts in ABS.

LAYER HEIGHT
Recommended : 0.2mm

EXTRUSION WIDTH

Recommended : Forced 0.4mm

INFILL PERCENTAGE
Recommended : 40%

INFILL TYPE

Grid, Gyroid, Honeycomb, Triangle or Cubic.

WALL COUNT

Recommended : 4

SOLID TOP/BOTTOM LAYERS

Recommended : 5

SUPPORTS REQUIRED

None at all.

MICRON

INTRODUCTION

HOW TO GET HELP

If you need assistance with your build you can head over the DOOMCUBE Discord group and post your questions (typically in the « micron » channel). It is the primary development channel involving the Micron! You can also check the Github page for the latest releases.

https://github.com/hartk1213/Micronhttps://discord.gg/EAANfEk25f

5

MICRON

FRAME

6

MICRON

GETTING EXTRUSIONS TOGETHER Separate the extrusions you’re going to need for this section of the build. We’ve laid out all the parts you should have and highlighted the ones that will be used in the following sections.

GATHERING EXTRUSIONS

7

220 mm

300 mm

MICRON

Z RAIL

M2x6 BHCS

Z RAILS
The Z rails attach to the vertical extrusions before building the frame. Begin by loading the M2 nut traps which secure the Z rails to the vertical extrusions. Every other hole is more than adequate. Screw the nut traps to the rails using M2x6 BHCS, leaving them loose enough so they may be easily slid into place on the extrusions. We will align and secure them in the next step.

MICRON

Z RAILS ALIGNMENT
Stand up one of the vertical extrusions and use the printed rail alignment tool as shown to align the bottom of the rail. It should end up ~36mm from the bottom of the vertical extrusion. Use a second rail alignment tool on the upper half of the rail, using the section marked ‘7’, to properly center the rail on the extrusion. Repeat this process for all 4 Z extrusions and rails.

8

~36mm

Z RAIL STOPS | MICRON

M3x8 BHCS

M3x8 BHCS

RAIL STOPS
After the 4 Z rails have been installed. Using an M3x8 BHCS install the rail stops on both ends of the Z rails.

9

BLIND JOINTS AND PRINTED NUT HOLDERS

10

BLIND JOINTS
BLIND JOINT ASSEMBLY DESCRIPTION.

MICRON

M3x8 BHCS

NO DROP NUTS (OPTIONAL)
To make it easier to align the preloaded nuts, you can use the printed holders referred to from now on as NDN that keep them from falling out.

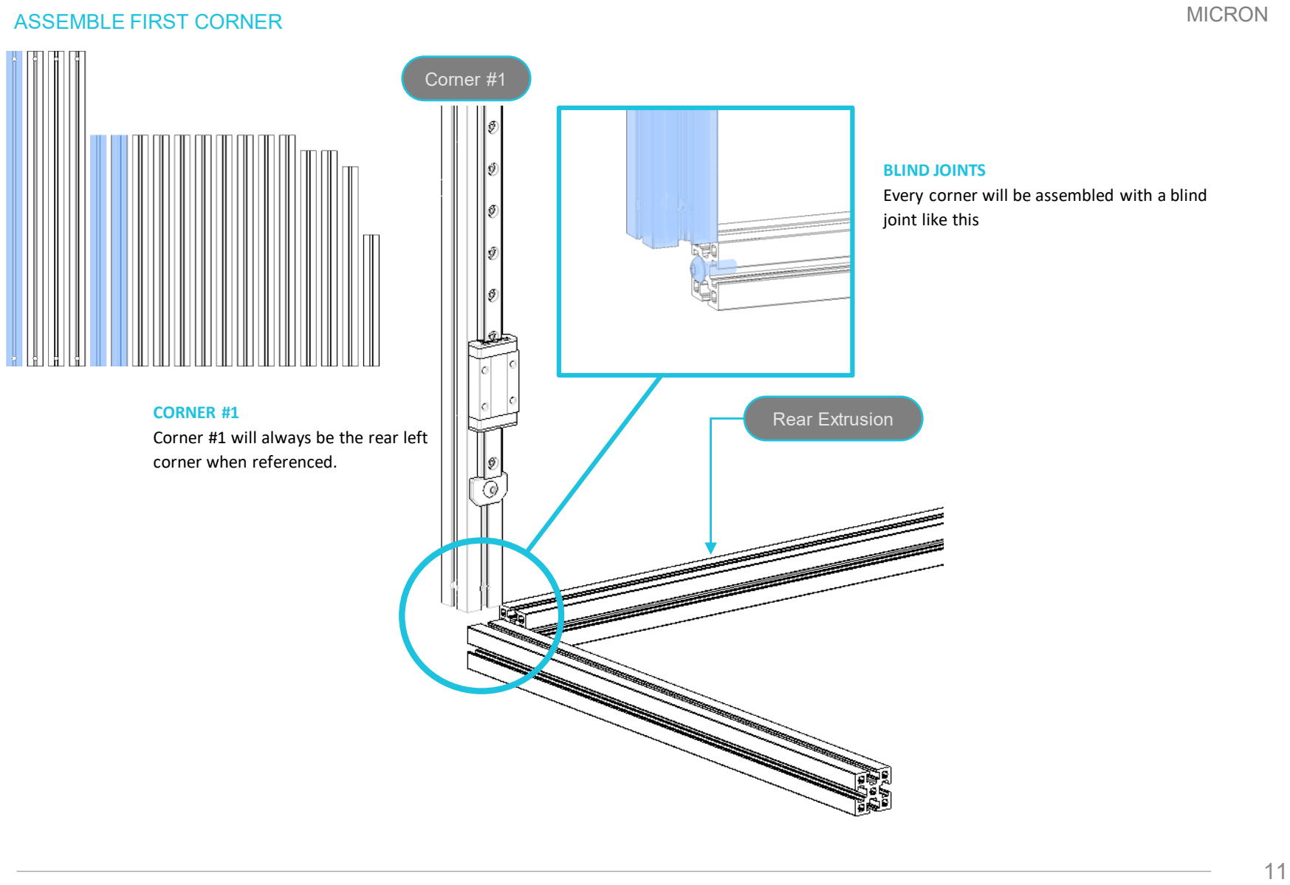
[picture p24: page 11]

ASSEMBLE FIRST CORNER | MICRON

11

Corner #1

Rear Extrusion

BLIND JOINTS
Every corner will be assembled with a blind joint like this

CORNER #1
Corner #1 will always be the rear left corner when referenced.

ASSEMBLE SECOND CORNER | MICRON

Preload 4 M3 nuts (top)

Preload 8 M3 nuts (bottom)

SECOND CORNER
Before attaching the 2nd vertical extrusion, you need to preload 4 m3 nuts on top, and 8 m3 nuts on the bottom of the extrusion.

12

Corner #1

Corner #2

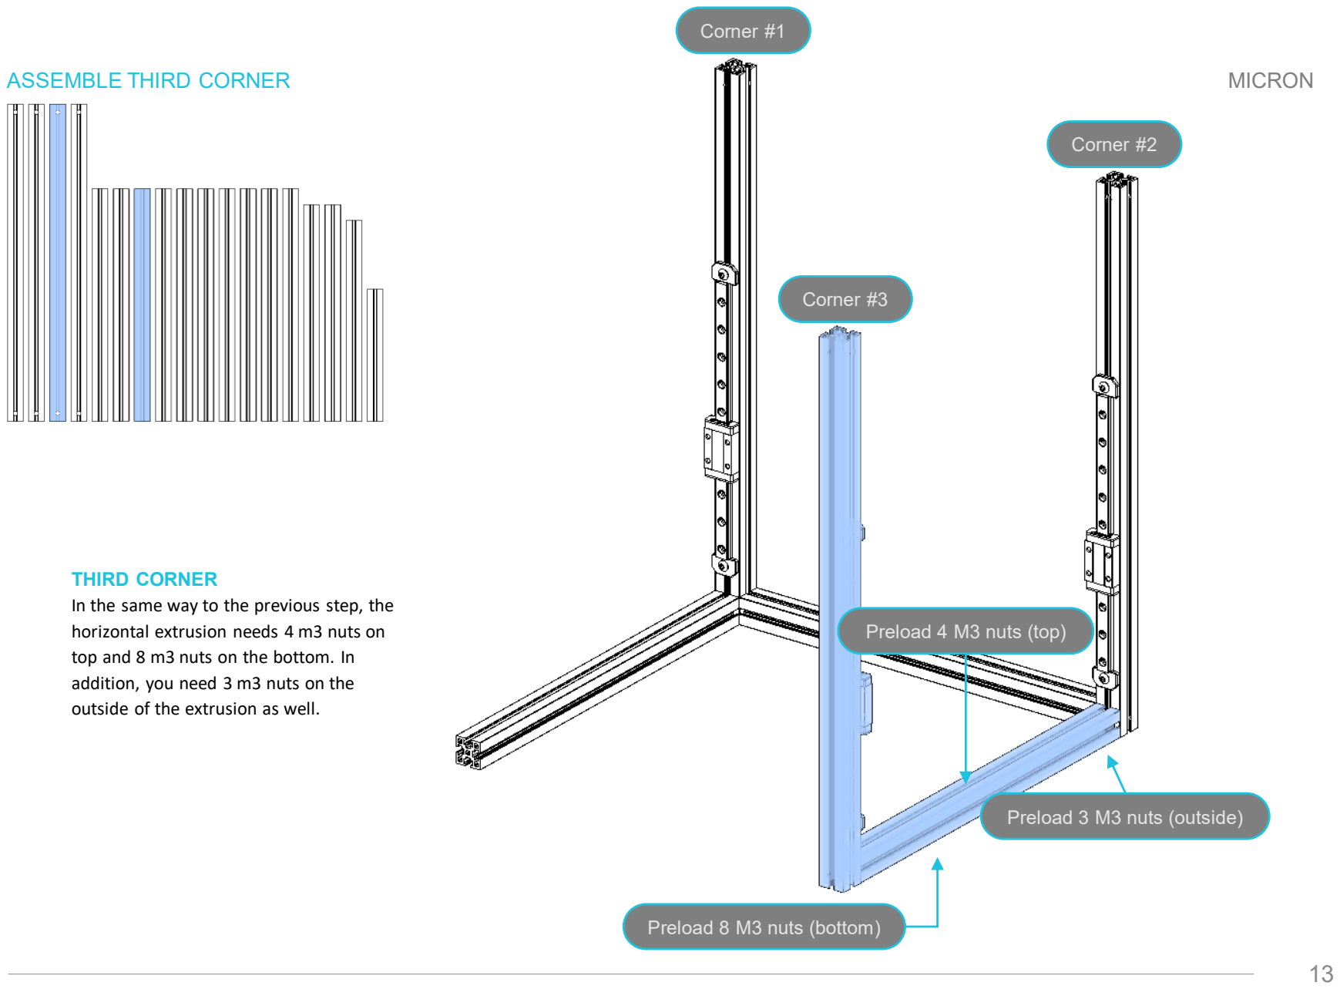
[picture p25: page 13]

ASSEMBLE THIRD CORNER | MICRON

Preload 8 M3 nuts (bottom)

THIRD CORNER
In the same way to the previous step, the horizontal extrusion needs 4 m3 nuts on top and 8 m3 nuts on the bottom. In addition, you need 3 m3 nuts on the outside of the extrusion as well.

Preload 3 M3 nuts (outside)

13

Corner #1

Corner #2

Corner #3

Preload 4 M3 nuts (top)

MICRON

Preload 2 M3 nuts (top)

Preload 8 M3 nuts (bottom)

14

Preload 8 M3 nuts (bottom)

Preload 3 M3 nuts (outside)

Preload 4 M3 nuts (top)

Corner #1

Corner #2

Corner #3

FINAL LOWER EXTRUSION

FINAL LOWER EXTRUSION
The final lower extrusion which is located on the front needs 2 on the top, and 8 on the bottom, You also need to preload the nuts in the first side extrusion, which needs 4 on top, 3 on the outside, and 8 on the bottom

15

ASSEMBLE THE FOURTH CORNER | MICRON

FOURTH CORNER
The final vertical extrusion will now be installed.

Corner #1

Corner #2

Corner #3

Corner #4

TOP OF FRAME

16

MICRON

TOP OF FRAME
The first of the top extrusions needs 4 nuts on the inside, 3 on top, and 3 on the outside.

Preload 4 M3 nuts (inside)

Preload 3 M3 nuts (outside)

Preload 3 M3 nuts (top)

Corner #1

Corner #4

TOP OF FRAME

17

MICRON

TOP OF FRAME
The rear of the top extrusions needs only 3 nuts in the top of it

Preload 3 M3 nuts (top)

Corner #1

Corner #4

Corner #2

Corner #3

TOP OF FRAME

18

MICRON

Preload 3 M3 nuts (outside)

Preload 4 M3 nuts (inside)

Preload 3 M3 nuts (top)

TOP OF FRAME
The first of the top extrusions needs 4 nuts
on the inside, 3 on top, and 3 on the
outside. | PRELOADING NUTS
| If using the printed nut holder, this will be inserted on the inside , you will need 2 of the medium NDN to make up the 4 nuts that need to be inserted
Corner #1

Corner #4

Corner #2

Corner #3

FRAME

19

MICRON

Preload 3 M3 nuts (top)
TOP OF FRAME
The final top extrusion requires 3 preloaded nuts

Corner #1

Corner #4

Corner #2

Corner #3

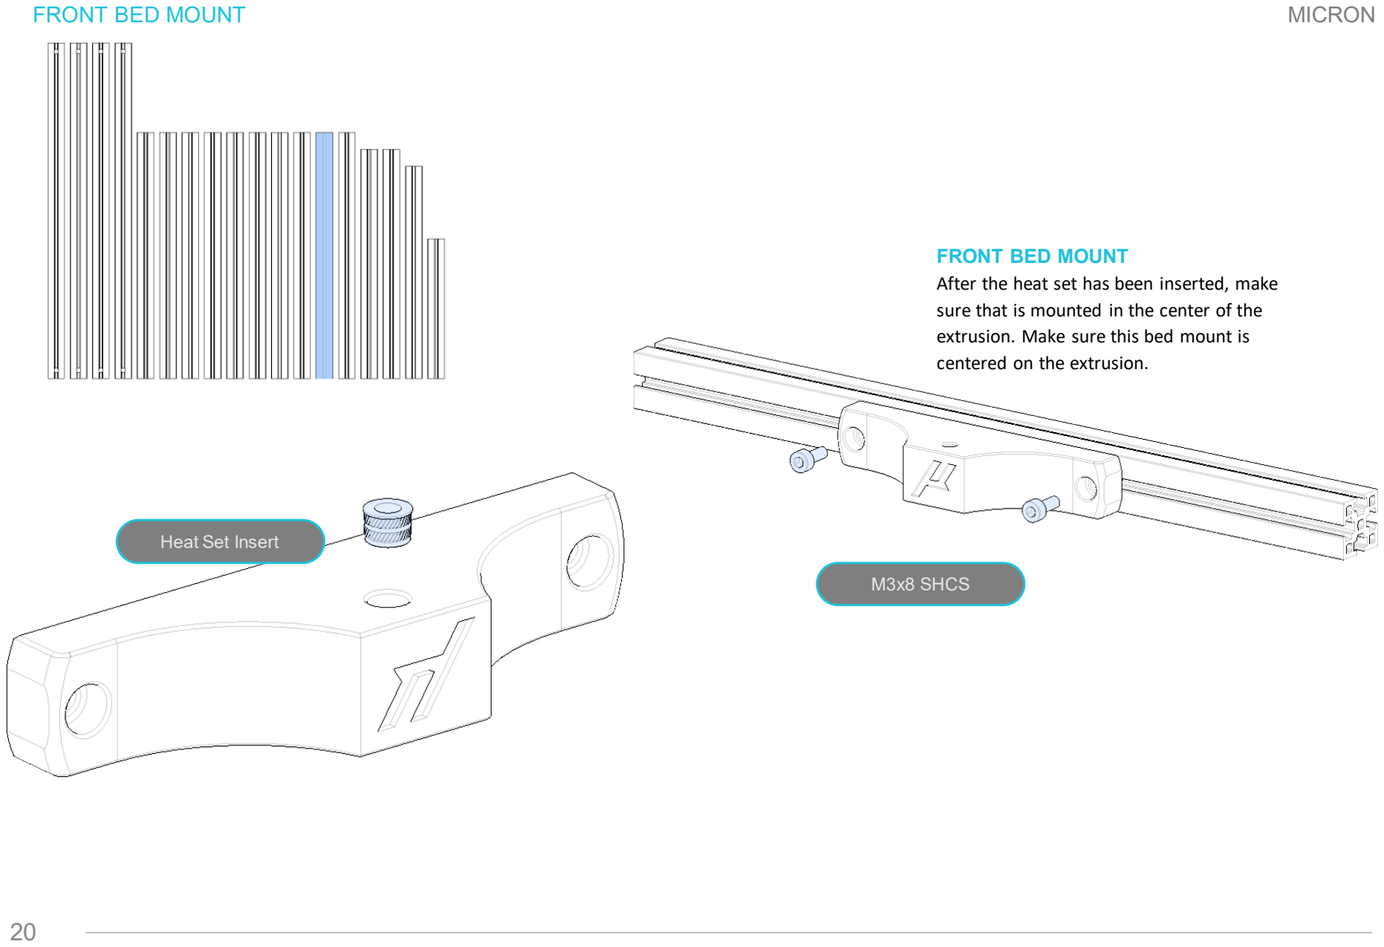
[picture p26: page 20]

FRONT BED MOUNT

20

MICRON

Heat Set Insert

M3x8 SHCS

FRONT BED MOUNT
After the heat set has been inserted, make sure that is mounted in the center of the extrusion. Make sure this bed mount is centered on the extrusion.

BED EXTRUSIONS

21

MICRON

M3x8 SHCS

BED EXTRUSIONS
Before you attach the 4 angled brackets, you need to make sure you preload all the M3 nuts. Then screw in the 1515 angled brackets to the ends of both bed extrusions using M3x8 SHCS

Preload 2 M3 nuts top

Preload 2 M3 nuts back

Preload 2 M3 nuts on bottom

BED ASSEMBLY

22

MICRON

BED EXTRUSIONS
Mount the bed extrusion as shown, making sure to space them out 45mm from the front and then 70mm apart

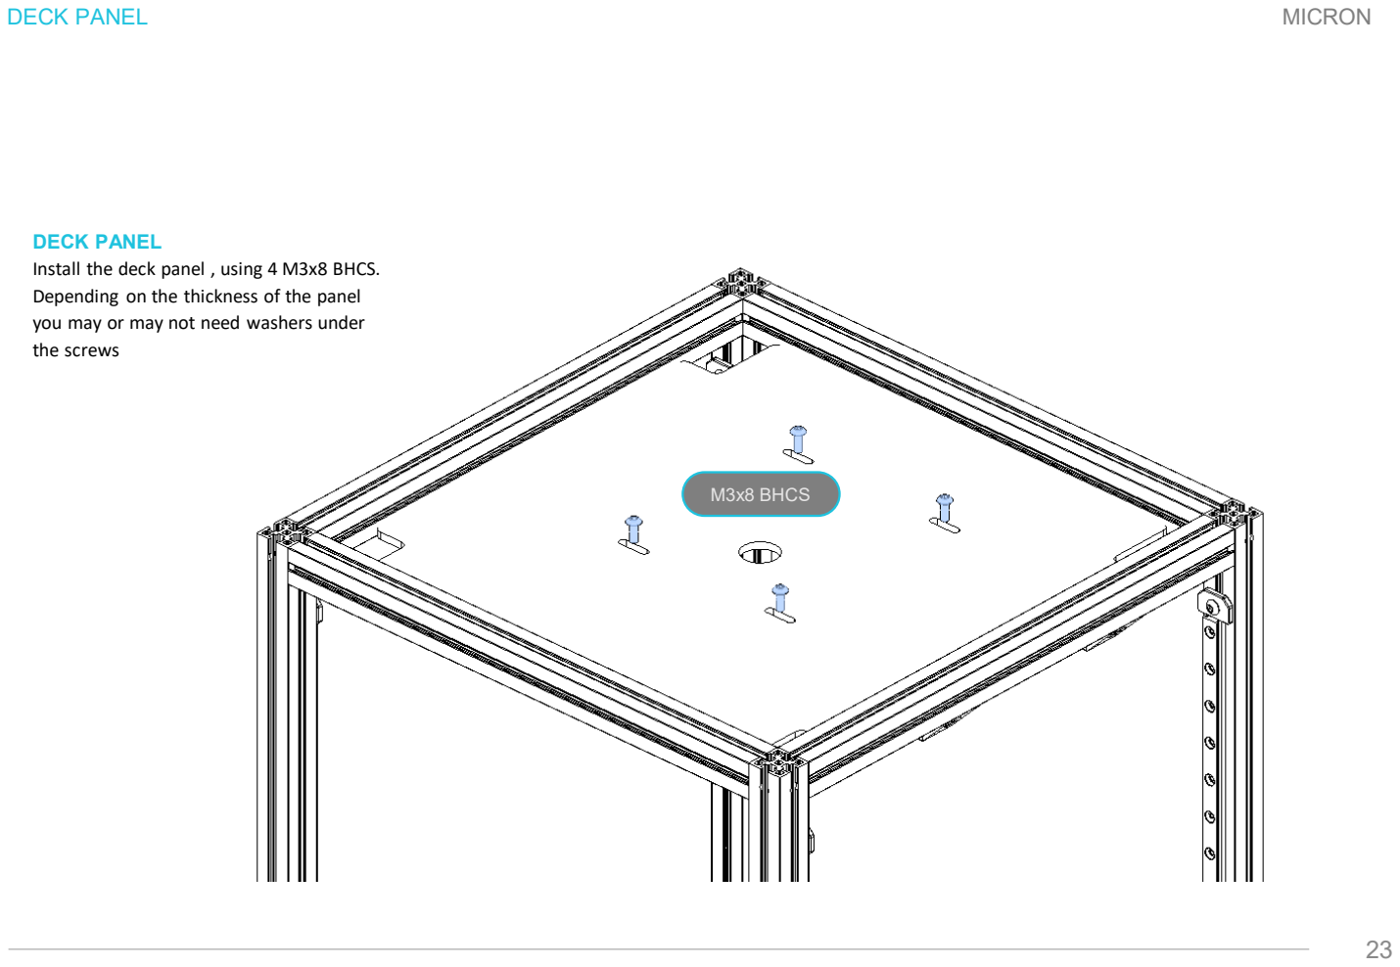
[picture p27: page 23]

DECK PANEL

23

MICRON

M3x8 BHCS

DECK PANEL
Install the deck panel , using 4 M3x8 BHCS. Depending on the thickness of the panel you may or may not need washers under the screws

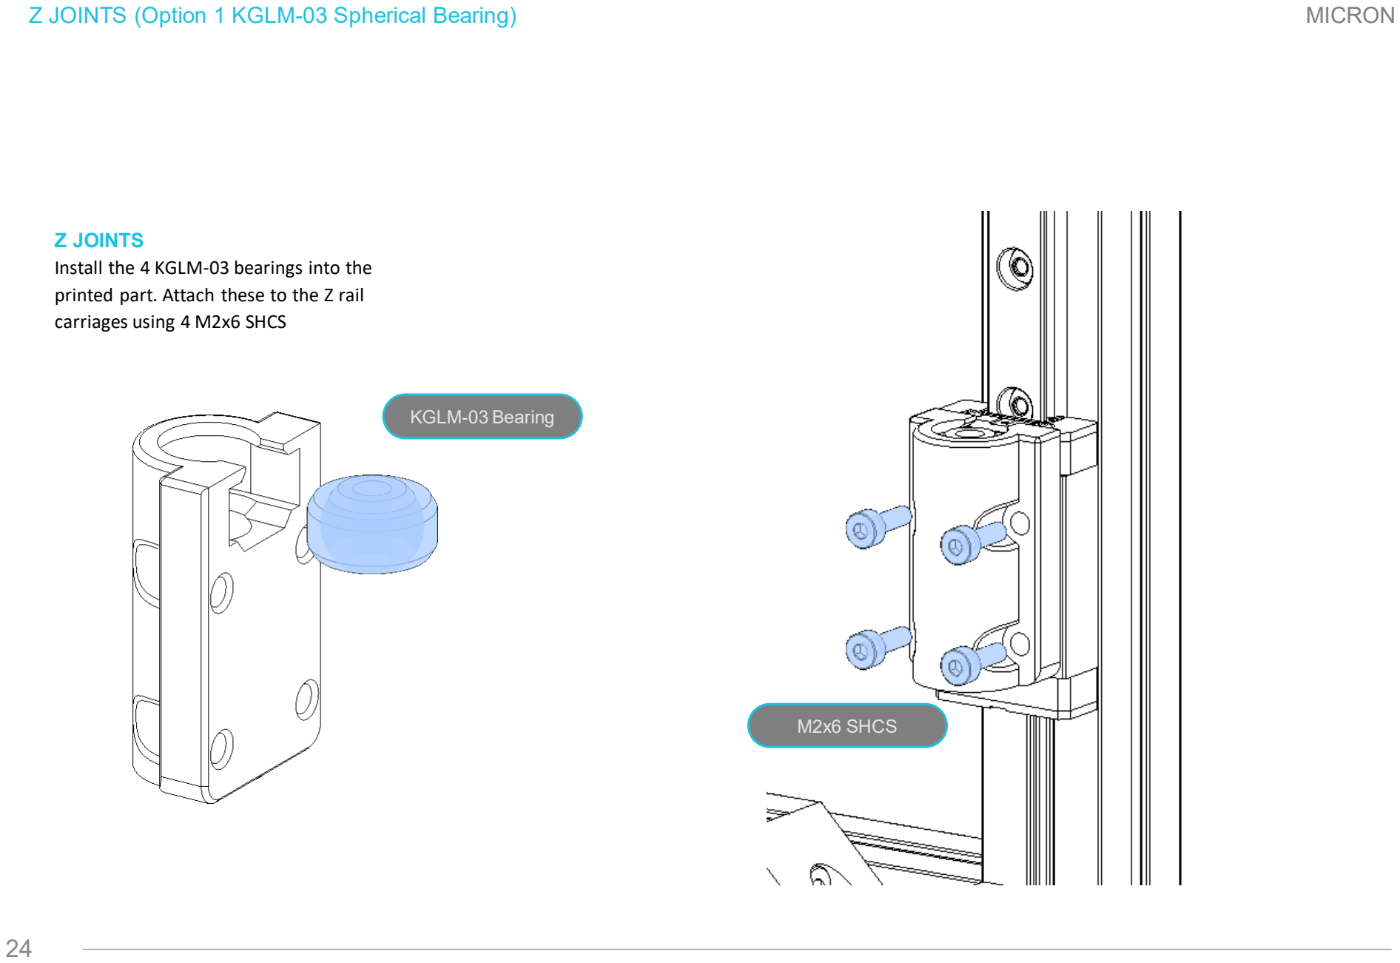
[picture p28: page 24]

Z JOINTS (Option 1 KGLM-03 Spherical Bearing)

24

MICRON

KGLM-03 Bearing

M2x6 SHCS

Z JOINTS
Install the 4 KGLM-03 bearings into the printed part. Attach these to the Z rail carriages using 4 M2x6 SHCS

25

Z JOINTS (Option 2) | MICRON

Z JOINTS
Attach these to the Z rail carriages using 4 M2x6 SHCS

M3x20 BHCS

M2x6 SHCS

26

FRAME

FRAME

At this point your frame should be looking like this.

MICRON

MICRON

27

Z DRIVES

MICRON

28

Z DRIVE 64T PULLEY ASSEMBLY

ASSEMBLING 64T PULLEY
Assembly of the printed 64T pulley is simple. Observe that one side of the printed part is flat, and the other concave. Insert a deflanged 16T pulley into the socket on the concave side of the printed part, as shown below. Use 4 M3x6 grub screws to lock the two components together. Repeat for all 4 64T gears.

x4

M3x6 grub screw

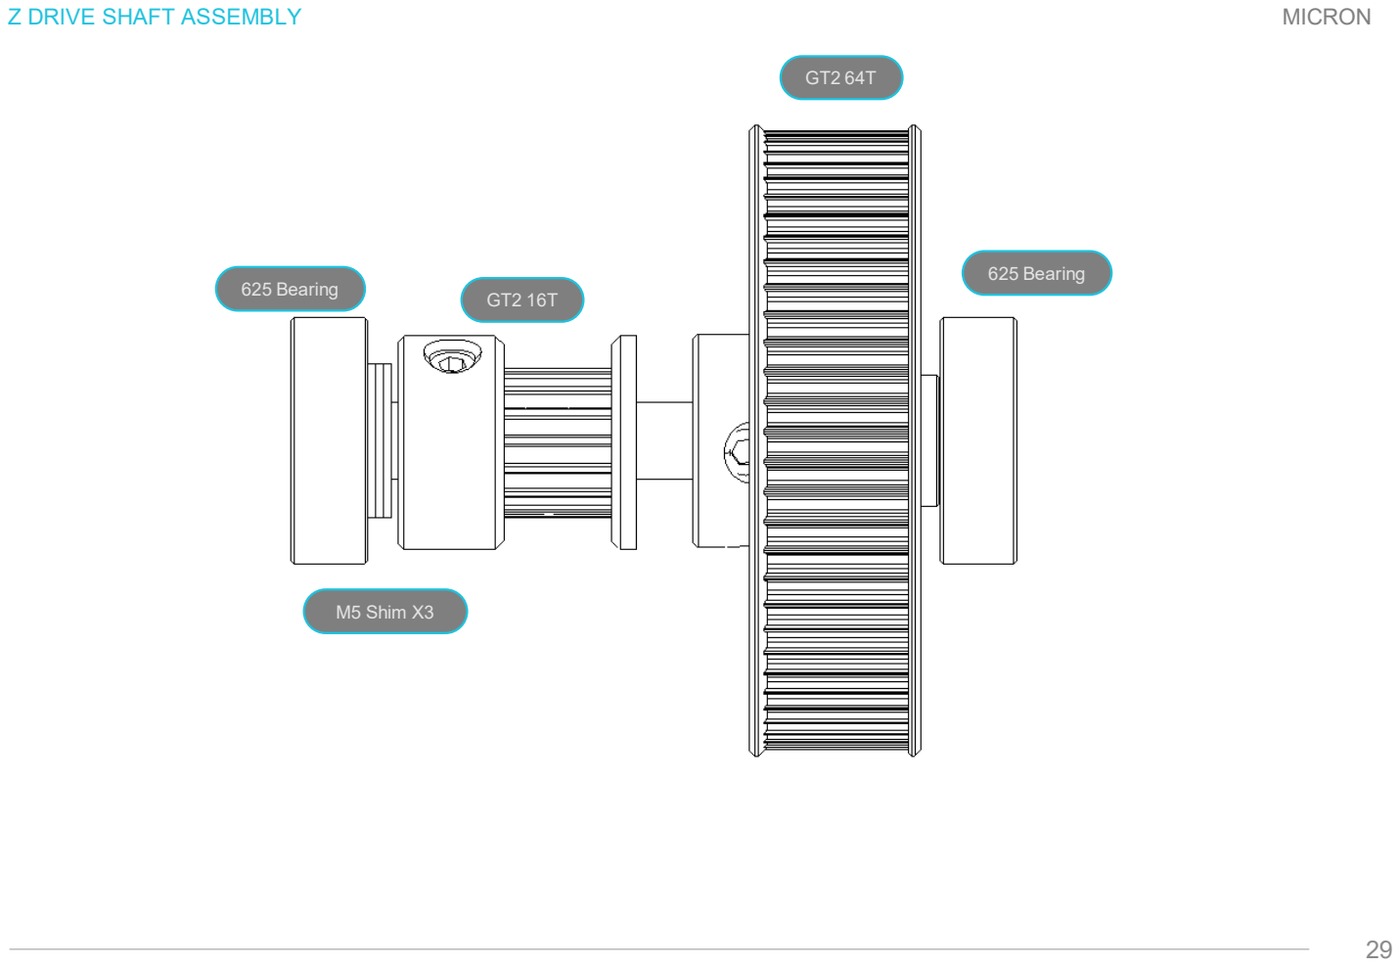
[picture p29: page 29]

MICRON

29

625 Bearing
625 Bearing | GT2 16T

GT2 64T

M5 Shim X3

Z DRIVE SHAFT ASSEMBLY

MICRON

30

Z DRIVE ASSEMBLY

Z DRIVE ASSEMBLY
Begin by installing the heatset inserts into the Z drive parts. Each pair of Z drive halves has a total of 8 required heatsets, as shown in the illustrations below.

M3 Heatset

M3 Heatset

M3 Heatset

Z MOTOR PULLEY ASSEMBLY | MICRON

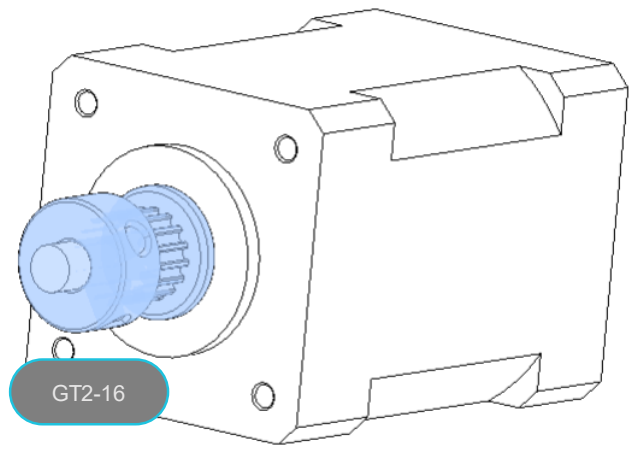
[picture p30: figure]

Z MOTOR PULLEY
To continue with the Z drive assembly, attach a GT2 16T pulley as shown to each of the 4 Z motors. Tighten one of the set screw just tight enough to keep the pulleys from falling off. DO NOT USE LOCTITE AT THIS POINT! We will determine the precise positioning of these pulleys once the motors are mounted to the printer. For now, we are just putting the pulleys in place, so we don’t have to slide them on to mounted motors.

31

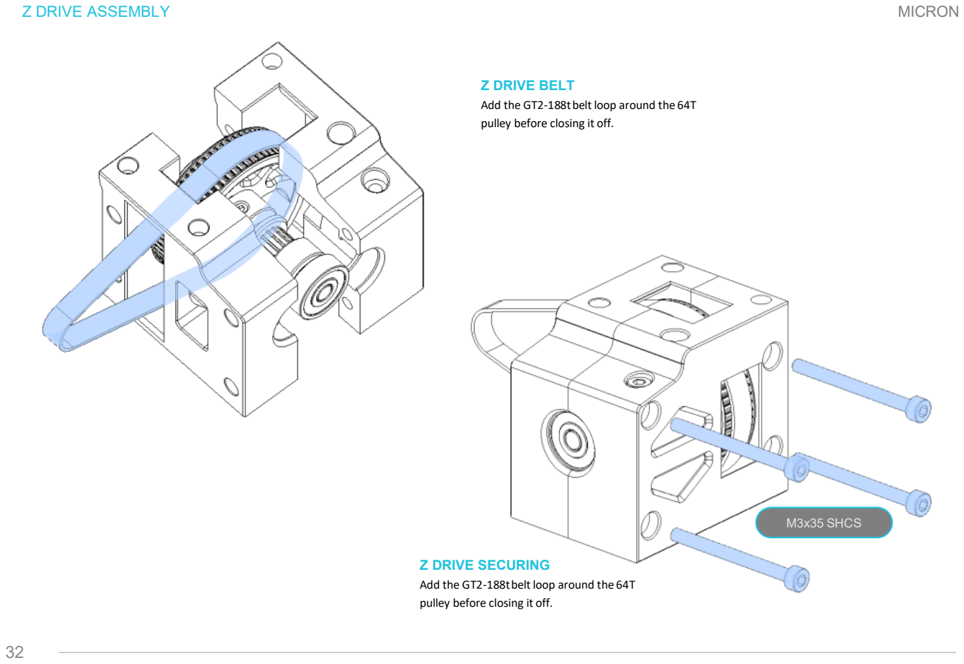
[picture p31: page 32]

Z DRIVE ASSEMBLY | MICRON

Z DRIVE BELT
Add the GT2-188t belt loop around the 64T pulley before closing it off.

Z DRIVE SECURING
Add the GT2-188t belt loop around the 64T pulley before closing it off.

M3x35 SHCS

32

Z MOTOR MOUNT | MICRON

Z MOTOR MOUNT
Z motor mount is best used with the wires for the z to be facing down or towards the inside of the printer
Note: The motor is on a slight angle in relation to the motor mount.

M3x12 SHCS

33

Z DRIVES MOUNTING | MICRON

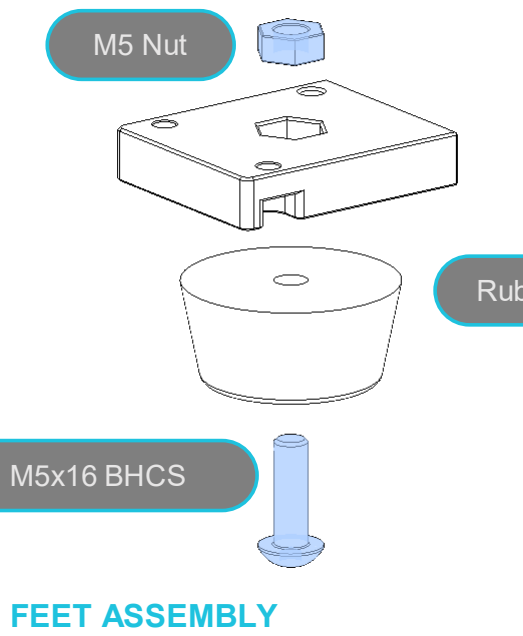
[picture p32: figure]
M5x16 BHCS; M5 Nut; FEET ASSEMBLY

Rubber Foot

To assembly the Z drive cap / feet, you need to

insert an M5 nut into the drive cover | FEET ASSEMBLY

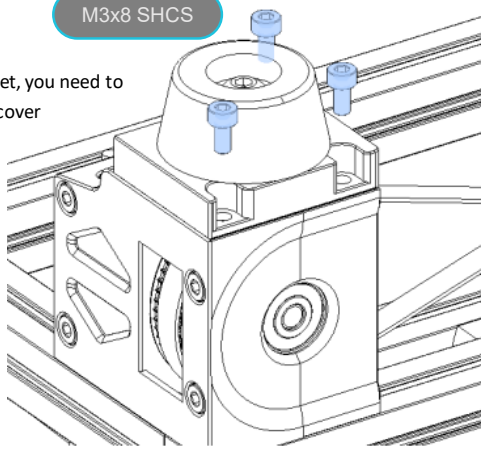
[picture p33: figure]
M3x8 SHCS

| To assembly the Z drive cap / feet, you need to
| insert an M5 nut into the drive cover

Z DRIVE MOUNT
Z Drive is mounted using the new M3x40 bolts. If you installed the printed NDN nut holder then this is where you will use that to secure the drive housing.

34

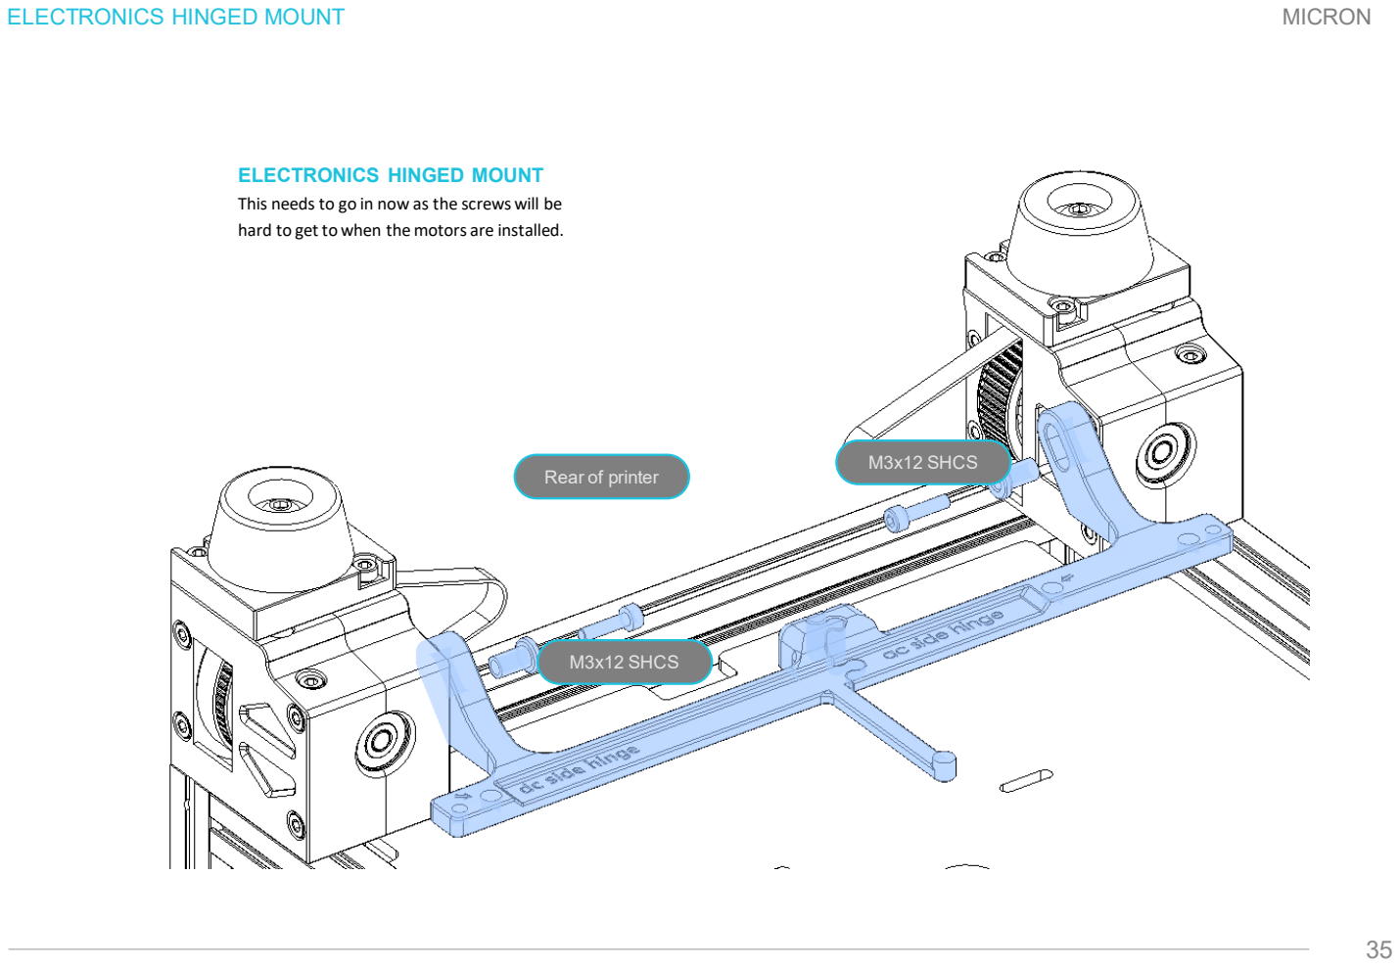
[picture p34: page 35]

MICRON

35

M3x12 SHCS

ELECTRONICS HINGED MOUNT

ELECTRONICS HINGED MOUNT
This needs to go in now as the screws will be hard to get to when the motors are installed.

M3x12 SHCS

Rear of printer

36

Z MOTOR MOUNTING | MICRON

Z MOTOR MOUNTING
Using 2 M3x8 BHCS and the printed nut holder on this side attach the Z motor. This is when you will tension the 188 tooth belt loop. The motor should be

37

Z IDLERS | MICRON

MICRON

38

Z IDLERS

Z TENSIONER
Slide the tensioner into the main body securing them together with an M3x16 BHCS and M3 hex nut.

Z TENSIONER PULLEY
Take the F623 bearing stack and place them between the idler securing them using an M3x20. Note the direction the screw is going.
F623 Bearing | M3x20 BHCS

M3x16 BHCS

x4

MICRON

39

Z IDLERS

Z IDLER MOUNTING
mounting the Z idlers on the top of the frame along the side extrusion. These can be mounted using the printed nut holders as well.

M3x20 BHCS

MICRON

40

Z ENDSTOP

MICRON

41

Z ENDSTOP ASSEMBLY

Sleeve Bearing

M4 Thumbscrew

M3 Spacers (x4)

5mm Binding Post Screw

Z Endstop PCB

M2x10 Self Tapping screws

MICRON

42

Z ENDSTOP MOUNTING

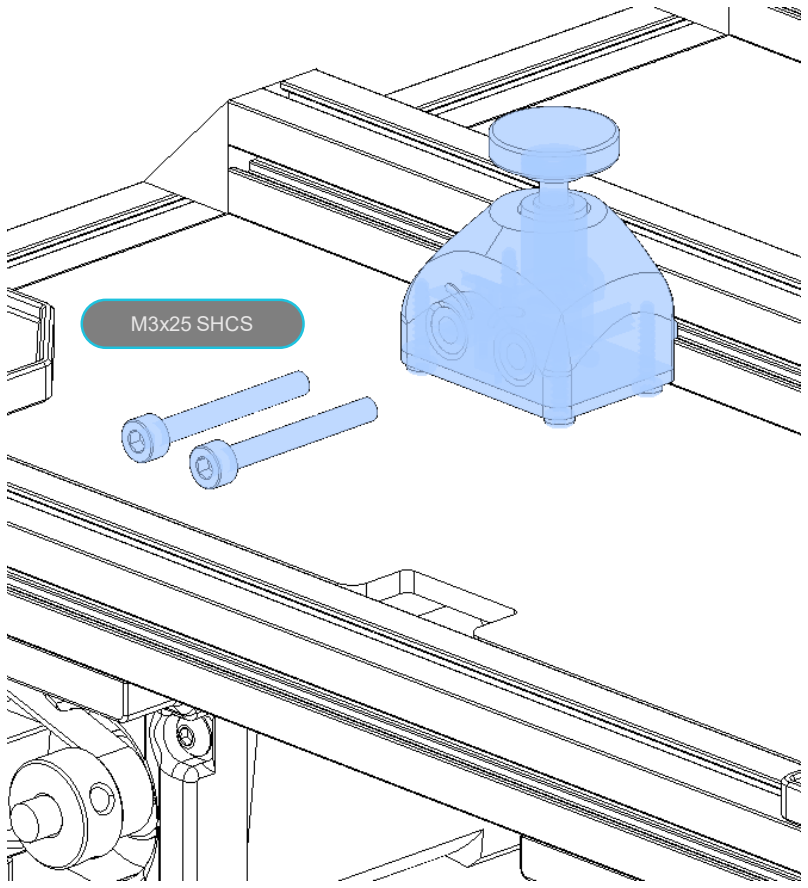
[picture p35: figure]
M3x25 SHCS

Z ENDSTOP MOUNTING
Mount the Z endstop along the back side of the rear bed extrusion, doesn’t really matter exactly where, as you will finalize that later with the firmware.

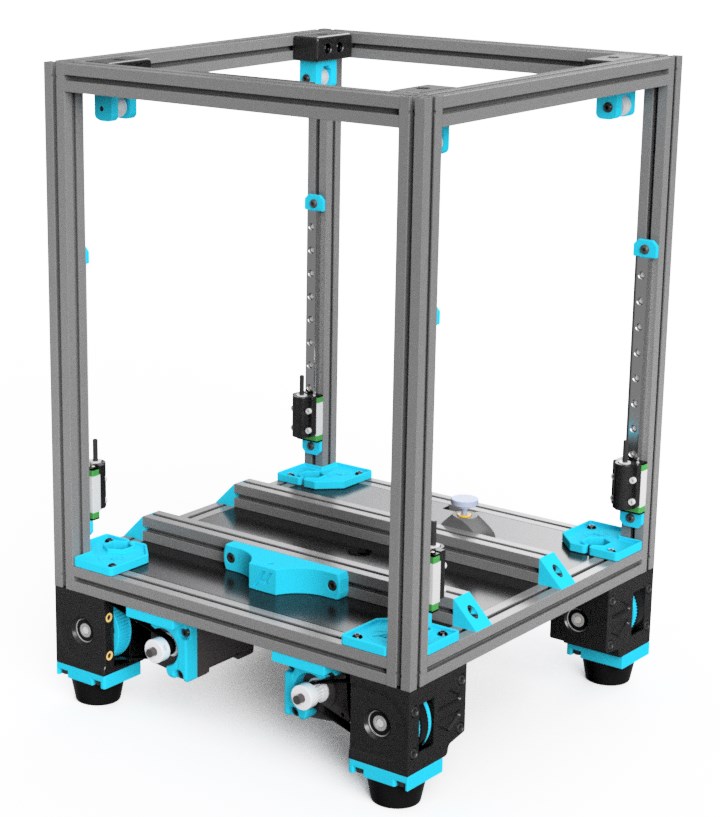
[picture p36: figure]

FRAME

43

MICRON

GANTRY

44

MICRON

Y AXIS LINEAR RAILS

45

MICRON

M2x6 BHCS

Y AXIS LINEAR RAILS
There are 2 linear rails on the Y-axis and they both need to be exactly in the center of the extrusions. If you measure the rail from the end of the extrusion it should measure ~27.5mm.

27.5mm from end

X AXIS LINEAR RAIL

46

MICRON

M3x8 SHCS

X Axis Linear Rail
As with the Y linear rail , the X rail also needs to be perfectly centered on the extrusion. The measurement from the end of the rail to end of extrusion is 20mm

20mm from end

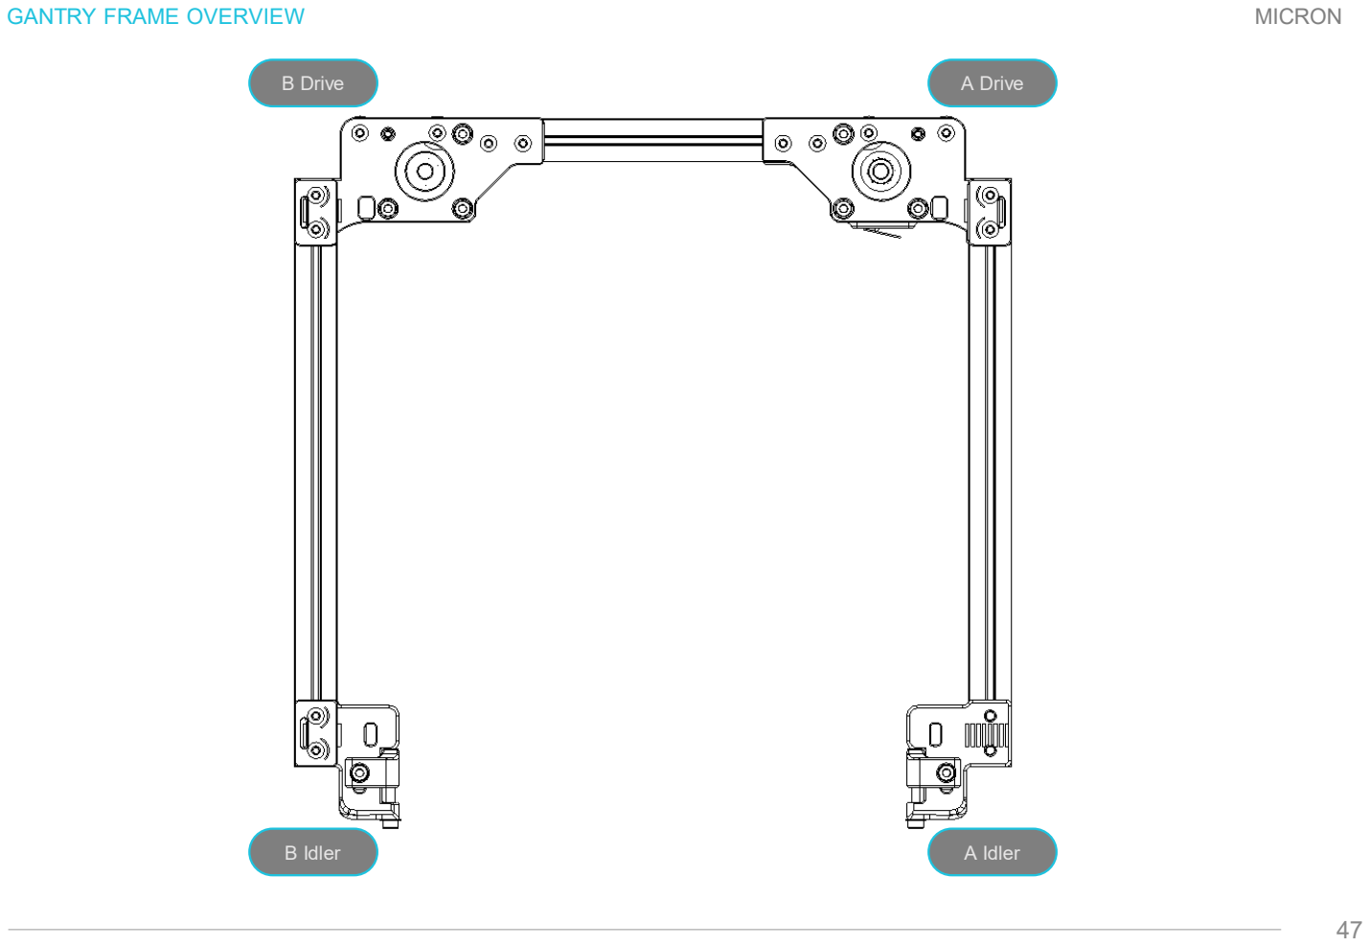
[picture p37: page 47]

GANTRY FRAME OVERVIEW

47

MICRON

B Drive | A Drive
B Idler | A Idler

A/B IDLERS

48

MICRON

M3 Heatset

M3 Heatset | M3 Heatset
A Tensioner | B Tensioner

A/B IDLERS

49

MICRON

M3x30 SHCS

F623 Bearing | M3 Shims

ASSEMBLY AID
This screw is used to align components and will be removed in a later step

A/B IDLERS

50

MICRON

REMOVE ASSEMBLY AID
Remove the assembly aid screw as you insert the tensioner screw and slide the tension arm into place.

M3x30 SHCS

M3 Washer

M3x35 SHCS

A DRIVE

51

MICRON

M3x6 BHCS
GT2-16

A MOTOR PULLEY
To attach the A drive stepper, orient the motor so the wiring is facing in towards the middle of the printer . Using 1 m3x6 BHCS to secure the stepper to the lower half of the A drive. Install a GT2-16 tooth pulley on the stepper as shown. Don’t tighten it down just yet until you run the belts later in the assembly.

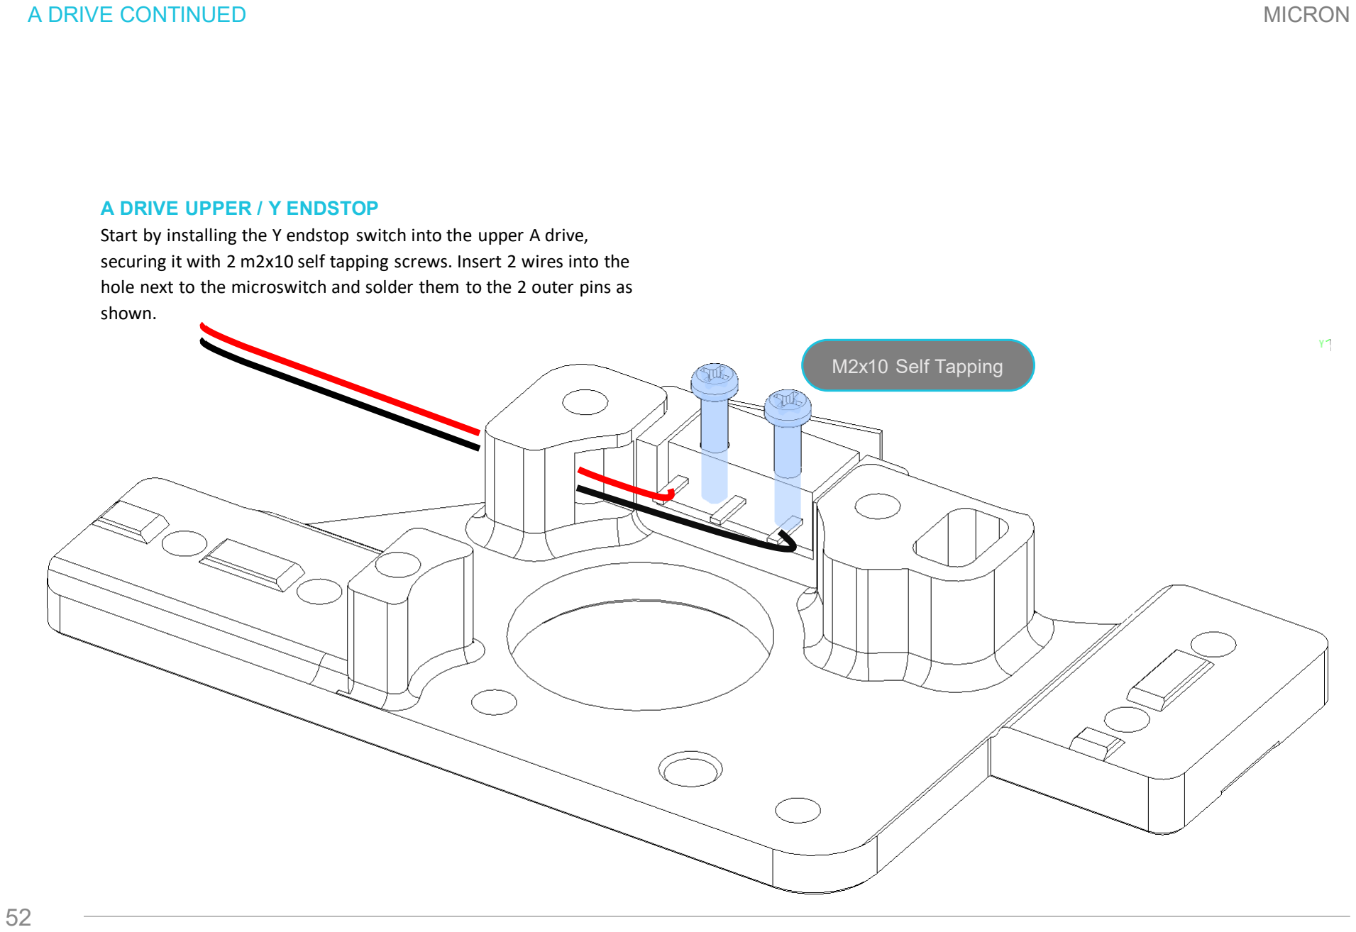
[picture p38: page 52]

A DRIVE CONTINUED

52

MICRON

A DRIVE UPPER / Y ENDSTOP
Start by installing the Y endstop switch into the upper A drive, securing it with 2 m2x10 self tapping screws. Insert 2 wires into the hole next to the microswitch and solder them to the 2 outer pins as shown.

M2x10 Self Tapping

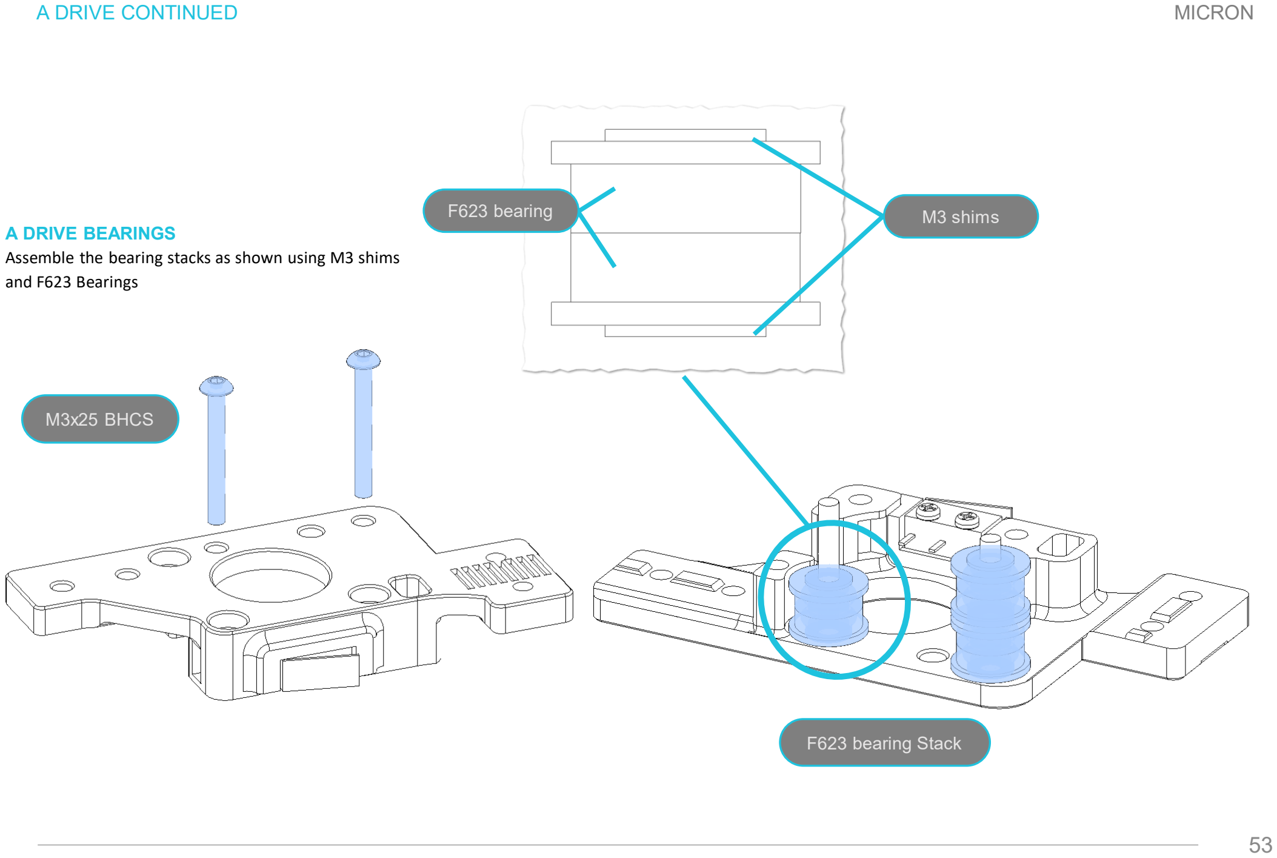
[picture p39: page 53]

A DRIVE CONTINUED

53

MICRON

M3x25 BHCS

F623 bearing Stack

A DRIVE BEARINGS
Assemble the bearing stacks as shown using M3 shims and F623 Bearings
F623 bearing | M3 shims

A DRIVE CONTINUED

54

MICRON

M3x25 SHCS | A DRIVE PULLEY Now is time to align the drive pulley with the top bearings and tighten the grub screw.

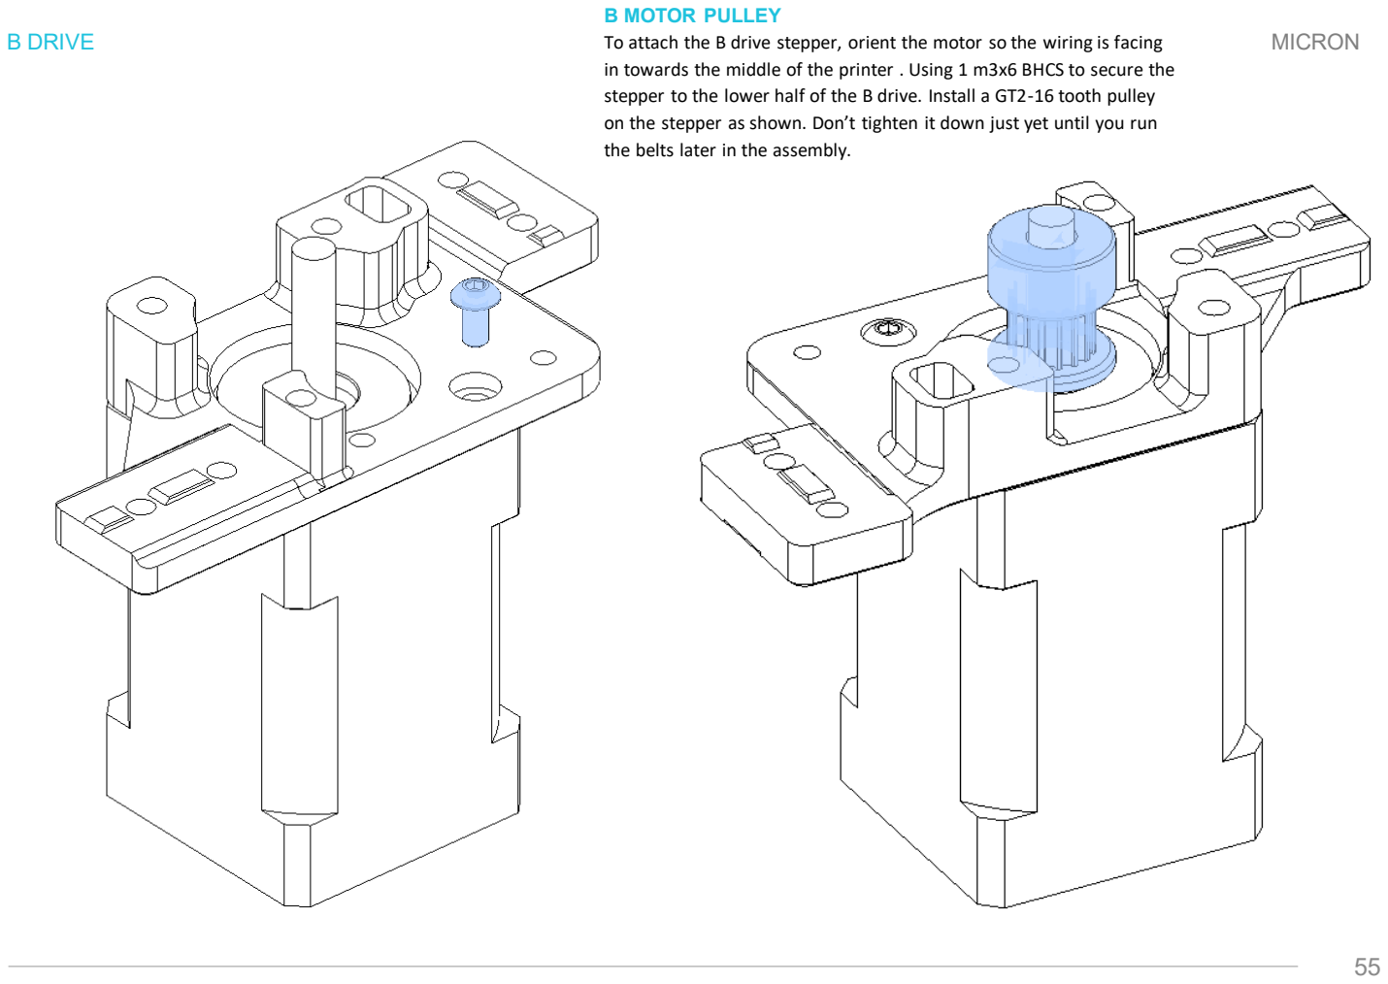
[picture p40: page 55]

B DRIVE

55

MICRON

B MOTOR PULLEY
To attach the B drive stepper, orient the motor so the wiring is facing in towards the middle of the printer . Using 1 m3x6 BHCS to secure the stepper to the lower half of the B drive. Install a GT2-16 tooth pulley on the stepper as shown. Don’t tighten it down just yet until you run the belts later in the assembly.

TEMPLATE

56

MICRON

M3x25 BHCS

B DRIVE BEARINGS
Assemble the bearing stacks as shown using M3 shims and F623 Bearings
F623 bearing | M3 shims

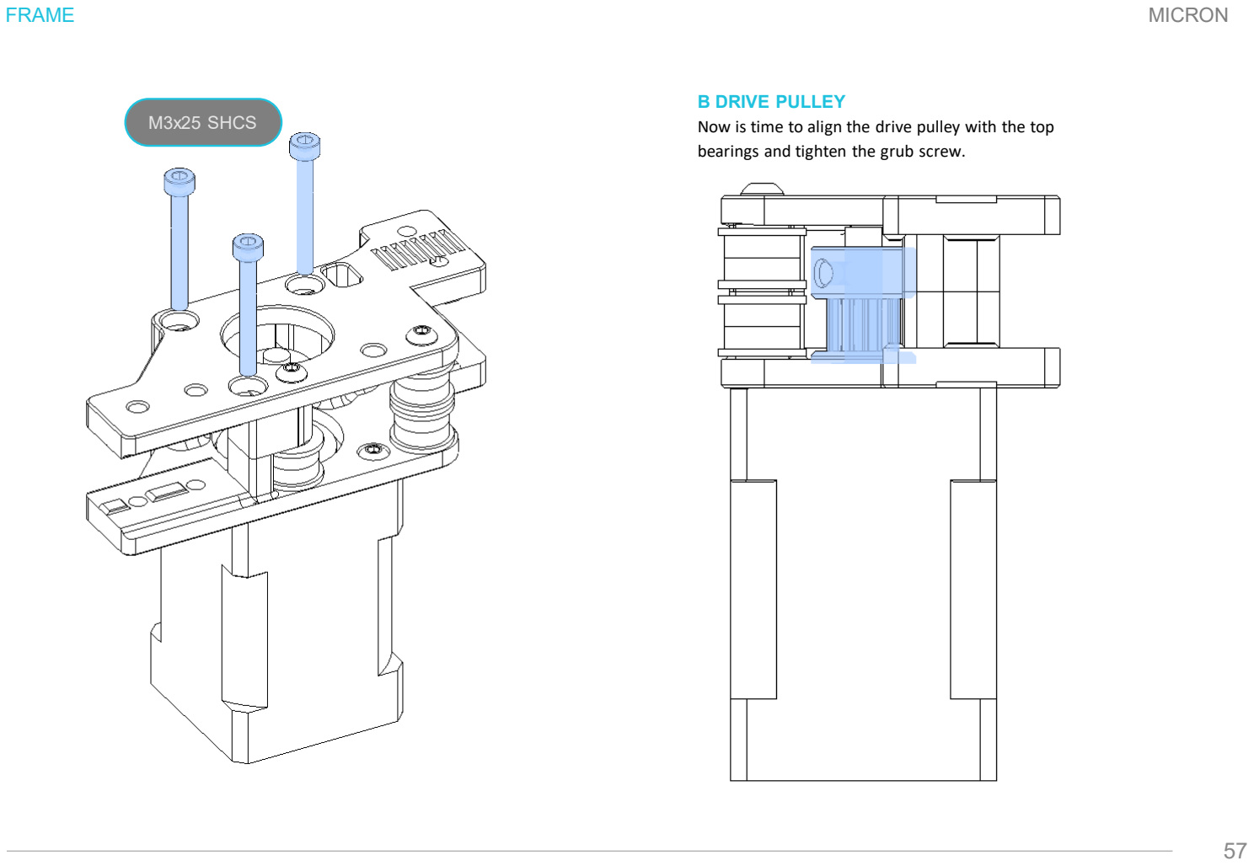
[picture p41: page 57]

FRAME

57

MICRON

B DRIVE PULLEY
Now is time to align the drive pulley with the top bearings and tighten the grub screw.

M3x25 SHCS

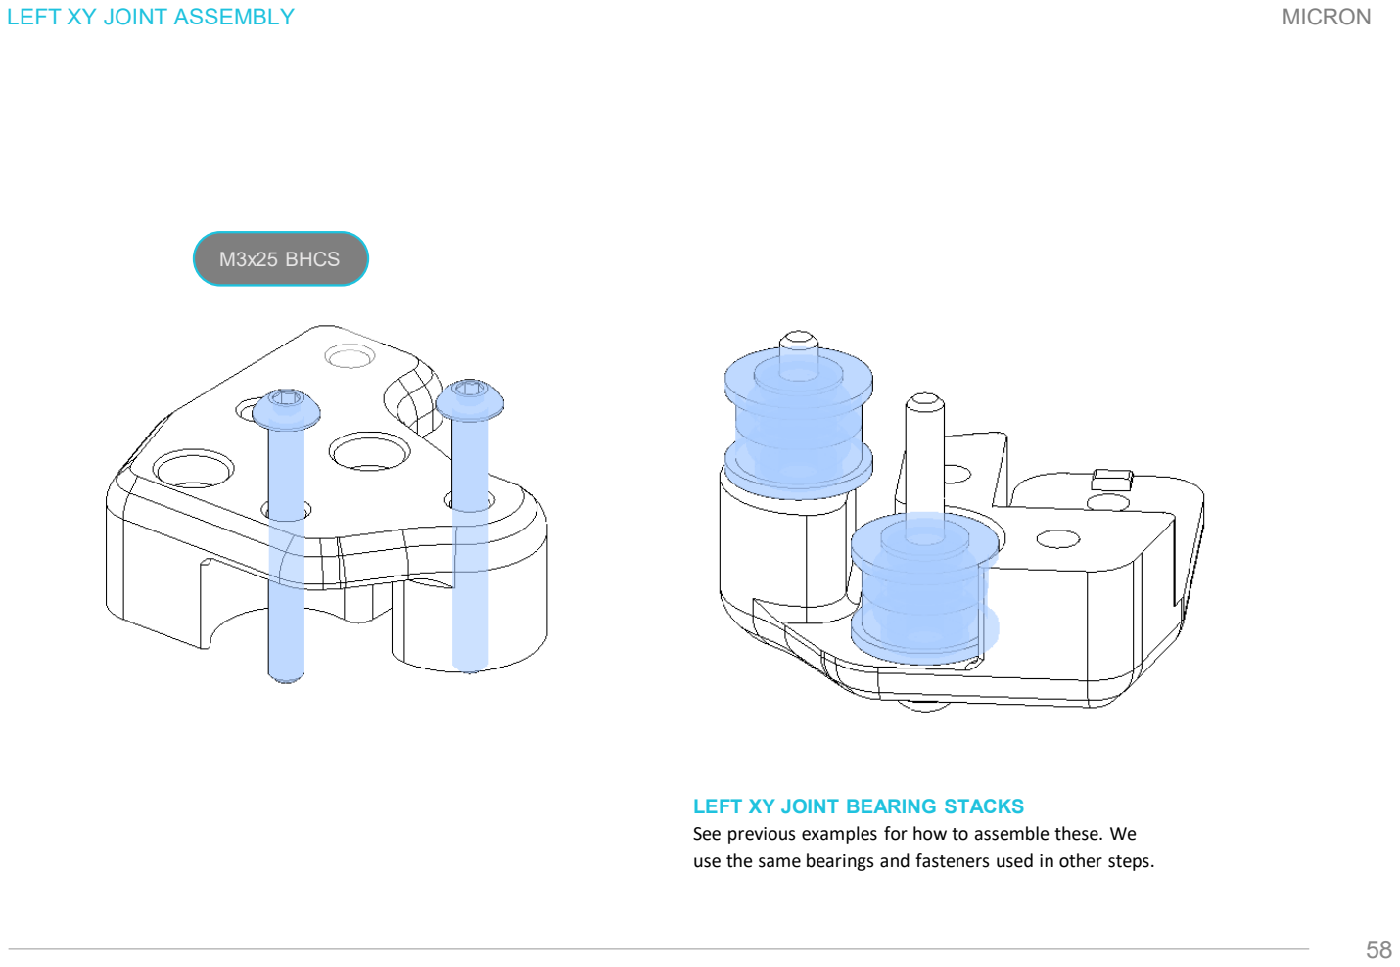
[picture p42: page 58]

LEFT XY JOINT ASSEMBLY

58

MICRON

M3x25 BHCS

LEFT XY JOINT BEARING STACKS
See previous examples for how to assemble these. We use the same bearings and fasteners used in other steps.

LEFT XY JOINT CONTINUED

59

MICRON

M3 Heatset insert

M3x35 SHCS

RIGHT XY JOINT

60

MICRON

M3x25 BHCS

RIGHT XY JOINT BEARING STACKS
See previous examples for how to assemble these. We use the same bearings and fasteners used in other steps.

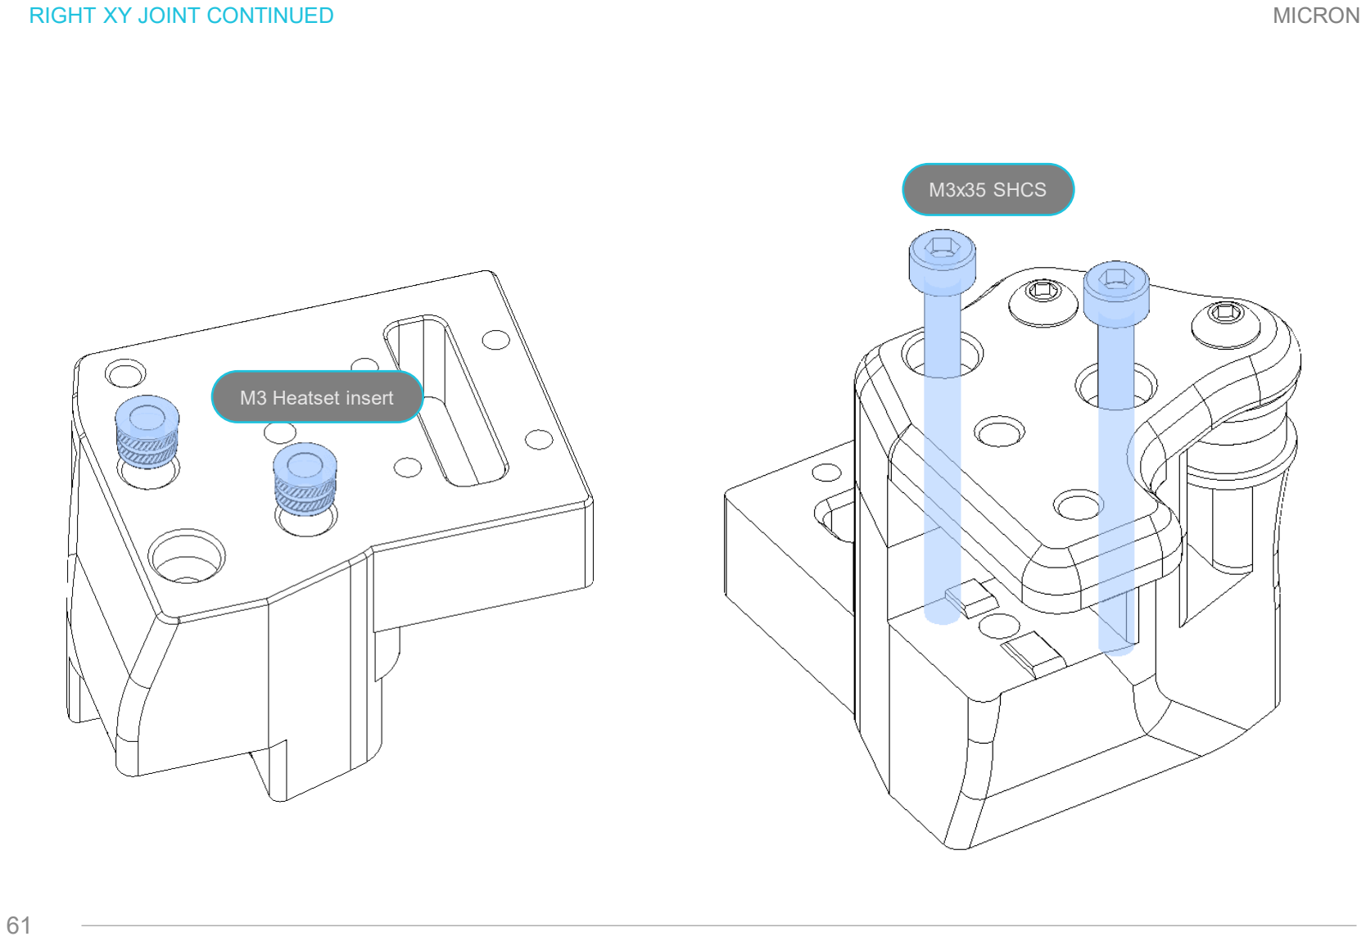
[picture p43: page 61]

RIGHT XY JOINT CONTINUED

61

MICRON

M3x35 SHCS

M3 Heatset insert

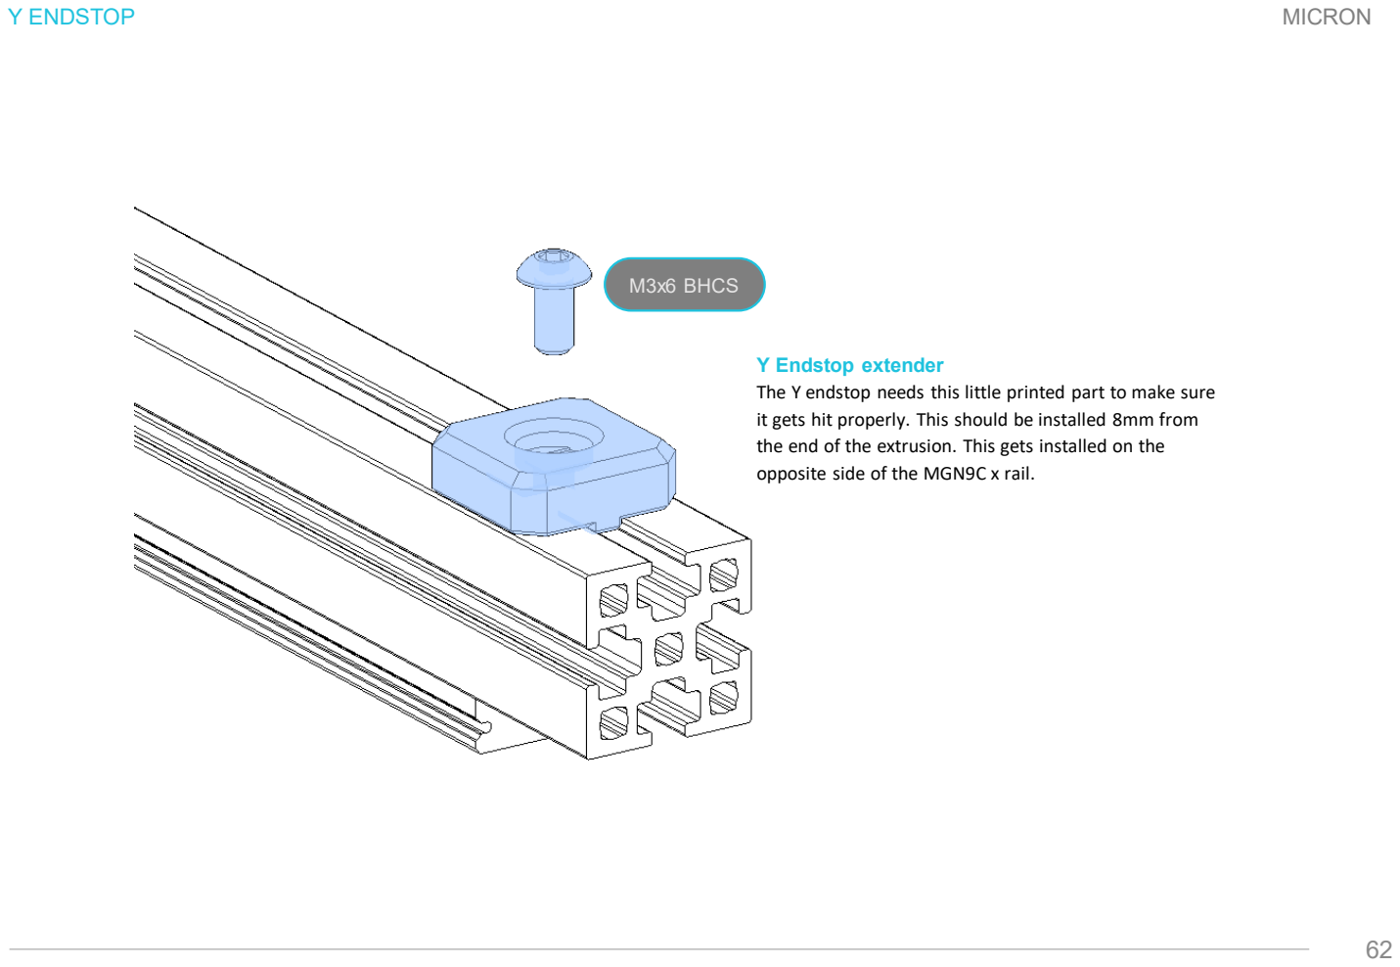
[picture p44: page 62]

Y ENDSTOP

62

MICRON

M3x6 BHCS

Y Endstop extender
The Y endstop needs this little printed part to make sure it gets hit properly. This should be installed 8mm from the end of the extrusion. This gets installed on the opposite side of the MGN9C x rail.

XY JOINTS

63

MICRON

M3x8 BHCS

M3x20 SHCS | M3x20 SHCS

M3x8 BHCS

AB IDLERS

64

MICRON

The front idlers need to be installed flush with the end of the Y gantry extrusions. These will also use the optional medium NDN if you are using those (12mm)

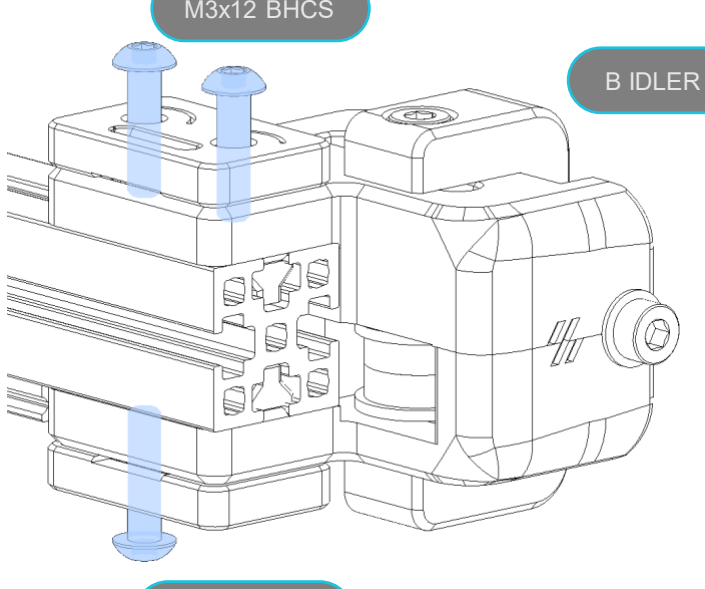
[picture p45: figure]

The belt clamps can go on now as well even though the z belts are not going in.

A DRIVE

65

MICRON

The rear of the A drive needs to be installed flush with the end of the Y gantry extrusions. These will also use the optional medium NDN if you are using those (12mm)

The belt clamps can go on now as well even though the z

B DRIVE

66

MICRON

Flush Install
The rear of the A drive needs to be installed flush with the end of the Y gantry extrusions. These will also use the optional medium NDN if you are using those (12mm)

M3x12 BHCS

M3x12 BHCS

Belt Clamps
The belt clamps can go on now as well even though the z belts are not going in.

KLICKY PROBE DOCK

67

MICRON

M3 Heatsets | M3x20 SHCS

6x3mm magnet

KLICKY PROBE

68

MICRON

6x3mm magnet

Omron D2F
6x3mm magnet

M2x10 Self Tapping

REAR GANTRY FRAME

69

MICRON

M3x8 BHCS

M3x8 BHCS

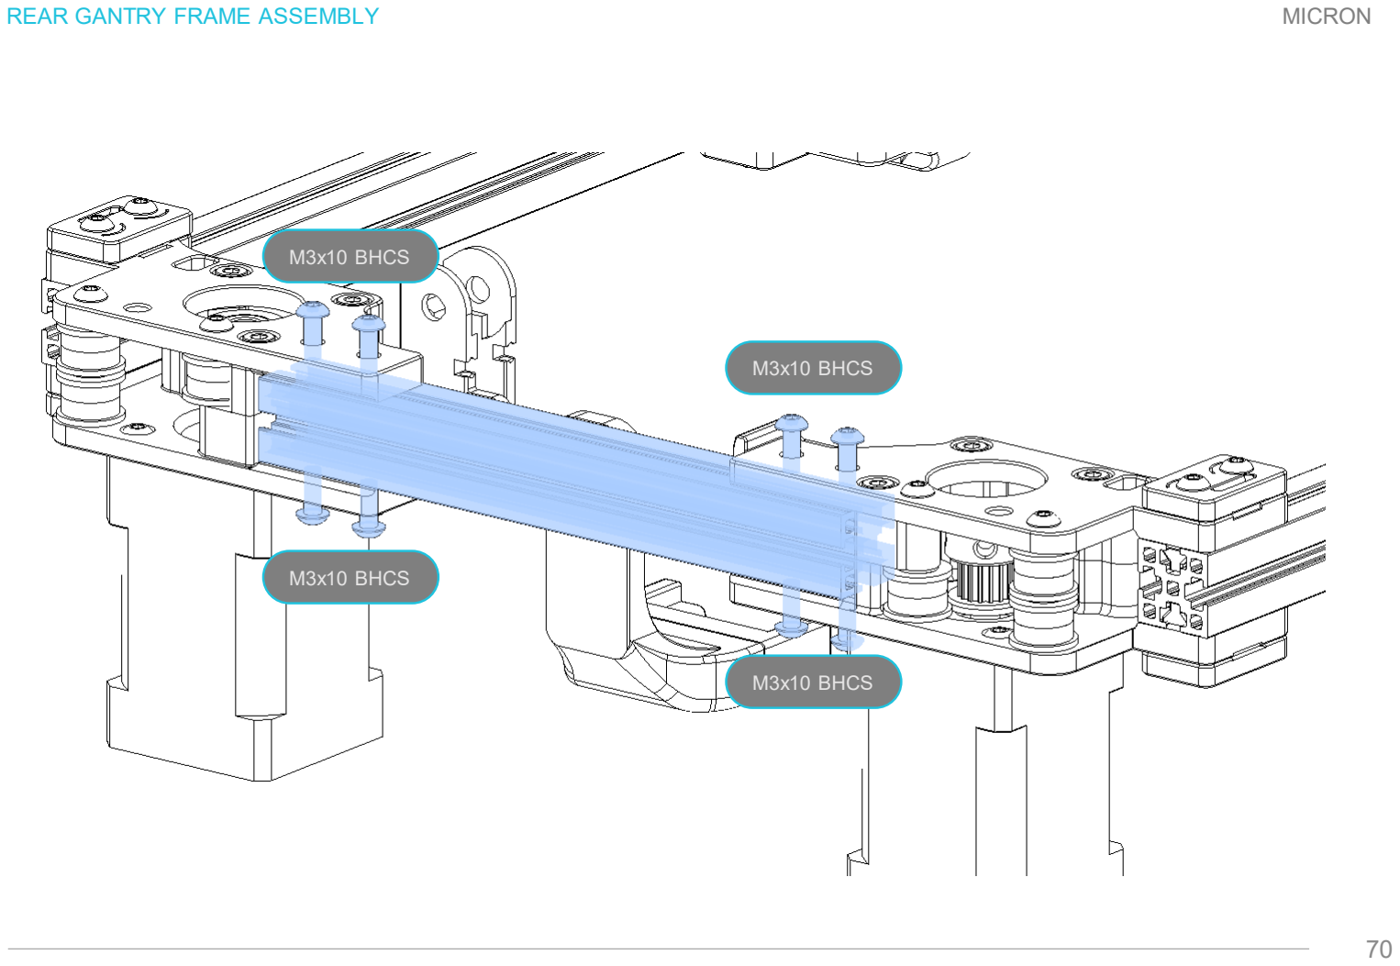
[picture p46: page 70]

REAR GANTRY FRAME ASSEMBLY

70

MICRON

M3x10 BHCS

M3x10 BHCS

M3x10 BHCS

M3x10 BHCS

X AXIS

71

MICRON

M2x12 SHCS

M2x12 SHCS

B DRIVE

72

MICRON

TEMPLATE

73

MICRON

B DRIVE

74

MICRON

TEMPLATE

75

MICRON

B DRIVE

76

MICRON

TEMPLATE

77

MICRON

B DRIVE

78

MICRON

TEMPLATE

79

MICRON

B DRIVE

80

MICRON

TEMPLATE

81

MICRON

B DRIVE

82

MICRON

TEMPLATE

83

MICRON

B DRIVE

84

MICRON

TEMPLATE

85

MICRON

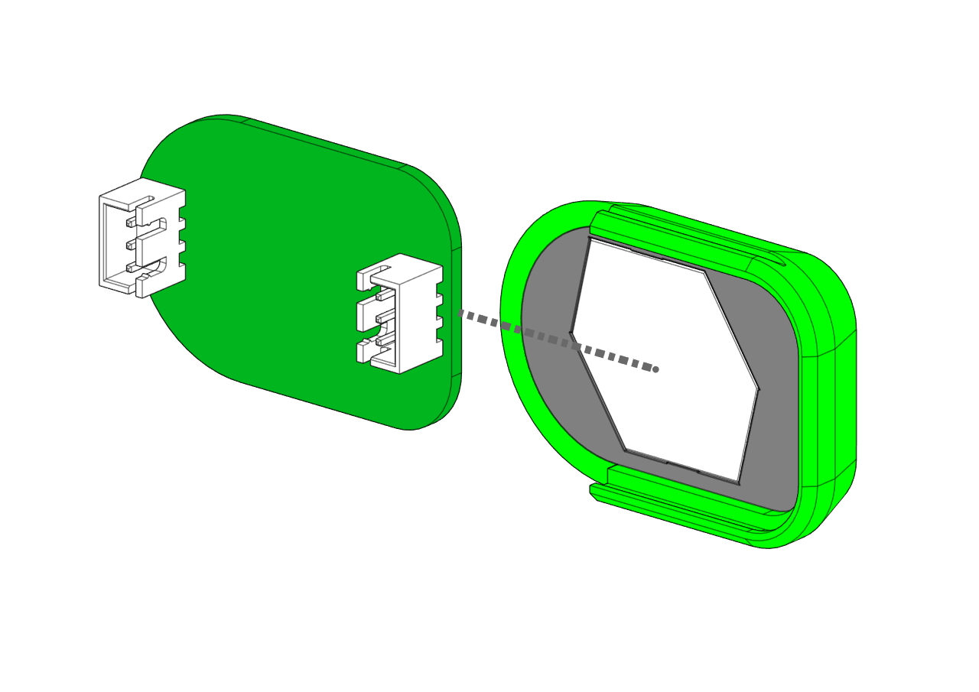
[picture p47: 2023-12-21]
Mods/pnewb/Skirt_LED_PCB/Images/Assembly/2.png

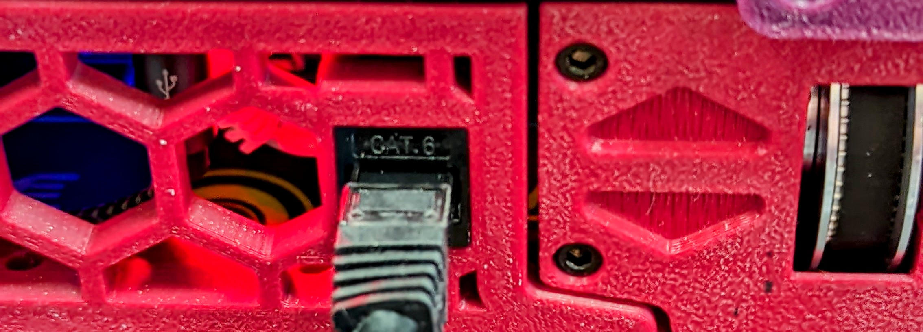
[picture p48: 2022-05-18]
Mods/gfunnymoney/MicronSideSkirtKeystonePort/images/installed.jpg

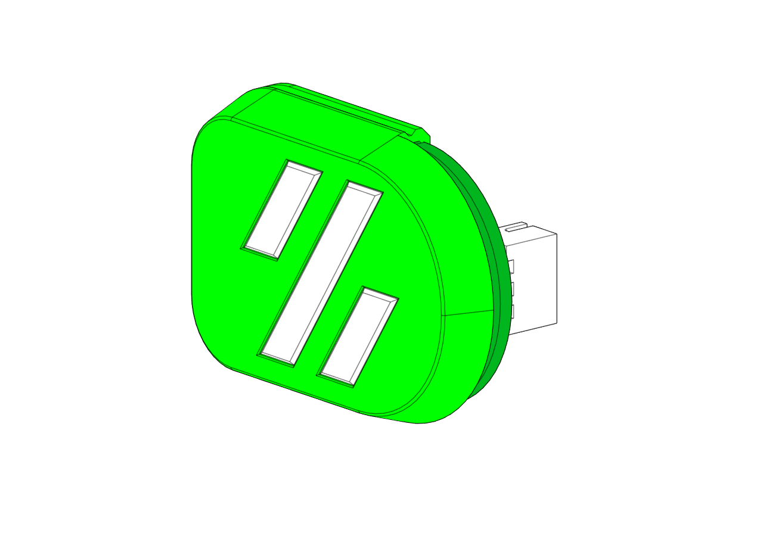
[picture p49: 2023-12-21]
Mods/pnewb/Skirt_LED_PCB/Images/Assembly/3.png

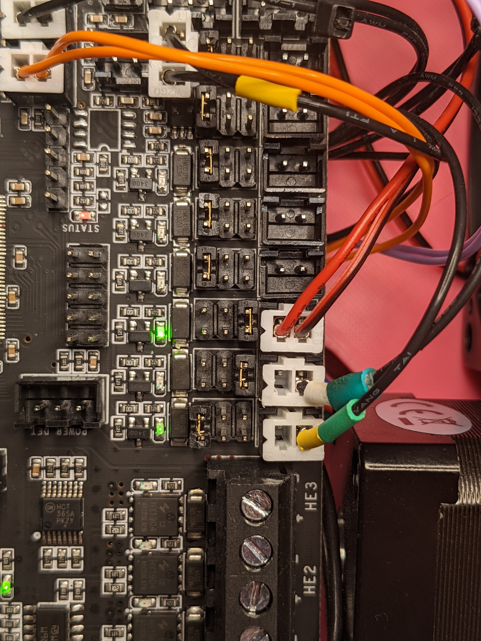
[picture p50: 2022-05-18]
Mods/L.e.o.p.a.r.d/Firmware/wiring_pics/micron_octopus_fan_detail.jpg

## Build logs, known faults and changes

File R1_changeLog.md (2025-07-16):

## Changes From R0 
### Gantry 
  * AB Drives
    * supports pinned bearings/pulleys or screws (pins are 25mm)
    * option for adding a top bearing support for stepper motor shafts (uses F695 bearings)
    * Fixed all belt path issues with the gantry
    * integrated Y endstop/sensorless endstop 
  * Gave every piece a low poly / stealthy look to them
  * Z Joints
    * updated KGLM z joints so they are less prone to cracking
    * Added Rigid Z joints
  * XY Joints
    * Stock build now uses Toothed idlers
    * supports pinned bearings/pulleys or screws (pins are 25mm)
    * option to use Live Idlers
  * Front Idlers
    * Implemented the BFI idlers for the AB belts
    * Modified the BFI idlers from clees repo to fix the belt path for the R1 gantry
    * supports pinned bearings or screws (pins are 14mm)
  * Rear Gantry Changes 
    * Swapped rear extrusion and Z chain to give more room for toolhead board wiring/umbilical
    * Removed support for the printed Z chain
    * Z-Chain guide now has chamber thermistor mount
    * New klicky probe dock that keys into the B drive
  * X Carriage
    * No changes to the X carriage
    * New probe mounts, now supports the following probes also includes a printed sensorless endstop bumper for X 
      * Beacon/Cartographer
      * Klicky
      * KlickyPCB
      * BIQU Microprobe
  * Toolhead 
    * [Anthead](https://github.com/PrintersForAnts/AntHead) is now the stock toolhead

### Z axis
  * Z Drives
    * Z drives now use 152mm belt loops to keep the entire assembly really compact
    * screw driven closed loop belt tensioning
    * supports nema14 / 17 (up to 52 mm long motors)
    * Option for G2Z Z drives now supported with matching skirts
  * Z Idlers
    * BZI idlers for the Z belts
    * Modified BZI to support both toothed idlers and bearing stacks (there are different parts named accordingly)
    * Option for live Idlers Z idlers
    * supports pinned bearings or screws (pins are 18mm)

### Panels/Door/Skirts
  * Door
    * New door hinge/ latch system that no longer needs the magnet latch on the inside of the printer
    * Door now needs 3mm foam to help seal the enclosure better
  * Panel clips
    * 2 new panel clip options 
    * Toolless twist lock panel clip
    * screwed on panel clips
    * There is a parametric panel clip [CAD file](https://github.com/PrintersForAnts/Micron/blob/main/CAD/SubAssemblies.zip) so you can get custom sized for your build if needed (stock uses 3mm foam and 3mm panels)
    * reverse bowden tube entry now has multiple versions for different types of collets
    * ptfe guide attaches via twist lock setup similar to panel clips
    * Spool holder is now 2 pieces so it can be stored flat when not needed
  * Bottom Panels screw holes have been moved (Bottom panel is not required in the build)
  * Z Belt Panel covers have been updated with a new insert to cover the hole to help keep out debris
  * Skirts
    * All new Skirts to match the new aesthetic
    * Rear Skirts
      * Rear skirt now includes 2 keystone slots
      * Option for filtered power Inlets
    * Front Skirt
      * Headless option now has all the hexes in the grid are centered correctly (previous version was not)
      * Added [BTT TFT35](https://s.click.aliexpress.com/e/_on454Nj) display mount
      * Added [Waveshare 4.3](https://www.waveshare.com/4.3inch-dsi-lcd.htm) and [BTT43](https://s.click.aliexpress.com/e/_oCLFmxB) mount (same mount for both displays)
    
### Accessories
  * Filter
    * New carbon filter added to mount under the bed
    * Uses a single 5015 fan for the filter
  * Bed heater / air circulation fans
    *   Dual 5015 bed fans
    *   Printed part replaces the stock Z belt covers on the front of the printer
  * Handles have been updated to be easier to mount , no longer need to be removed to remove top panel

## 
  
## Commit Change log ##

### 06-15-2025
* Added dedicated Pinned version for the front idler carrier 

### 04-15-2025
* added dual 5015 bed fan option
* updated filter cartridge and catridge lid to match the new bed fans
* updated CAD assembly to RC3 with all the latest changes

### 03-03-2025
* fixed [#148](https://github.com/PrintersForAnts/Micron/issues/148)
* fixed [#149](https://github.com/PrintersForAnts/Micron/issues/149)

### 02-05-2025
* added missing parts to the CAD assembly caused by a bad export 

### 01-28-2025
* fixed issue with bearings rubbing on the A drive
* closed up the Z belt holes in the AB drives and front idlers and made them more symmetrical

### 01-20-2025
* fixed issues #143 , #141, #138 , #137
* Updated CAD to RC1 status
* uploaded WIP manual with updated preloaded nut callouts 

### 10-17-2024
* Added G2Z Cad and organized all the STLS (Z drives and skirts) G2Z uses same foot mounts from R1Z and skirt accent pieces 
* fixed Pinned XY joints hole sizes to now all be 3.2mm 
* Updated latest assembly to include [Anthead](https://github.com/PrintersForAnts/AntHead)

### 9-20-2024
* increased tension travel on the front idlers by 5mm (from 3mm to 8mm) , minor changes to the front cover of the idler as well

### 9-18-2024
* fixed incorrect counterbore bridging on the rear bowden entry files (thanks to user named Yell for finding that)

### 9-12-2024
* added CNC gantry top bearing mount
* Updated all the umbilical mounts to accomodate the new top bearing mount, as it was interfearing
* removed the YC8 version of the umbilical
* updated cad assembly to v59 

### 9-10-2024
* Added new top bearing support for a double shear bearing on the AB motors 

### 9-5-2024
* cleaned up main cad assembly 
* posted link to fusion source assembly file to be downloaded
* adjusted gantry files to no longer need built in printed shim, now there are shims on both sides of every bearing stack 

### 9-3-2024
* added missing filter files 
* fixed naming issues on certain files 

### 9-2-2024
* added new under bed carbon filter
* started on CAD assembly clean up 
* renamed various files 

### 8-22-2024 
* cleaned up files

### 8-11-2024
* updated the Hula foot mounts to the latest version that works with the bottom panel
* added new TFT35 display front skirt 
* updated latest cad assembly v55
* removed old cad files no longer needed (moved hula cad files into main assembly)

### 8-2-2024
* organized panel clip files
* updated latest cad assembly v54
* added dual color rear bowden entry option

### 8-1-2024
* Updated Z drives for better printability to match new skirt accent pieces
* Added under bed filter from KyleGB to the main repo (still need STLs)

### 7-27-2024
* fixed waveshare accent pieces
* updated latest cad assembly v52
* updated skirts with new accent pieces as well as bottom panel mounting provisions

### 7-25-2024
* Updated z belt cover accent cover to fit better
* added twist lock panel clips for 3mm foam and panels
* fixed printing orientation for rail stops and umbilical mounts

### 7-23-2024
* Updated R1 Skirts to now include accent strips along the bottom as well as allow for a bottom panel to fit
* Updated skirts to they are all the same height , some had about ~1mm difference between them 
* Updated the waveshare mount to now us m2 self tapping screws instead of filament to keep bezel on 
* Updated Z drive foot mount to accommodate  bottom panel 

### 7-23-2024
* Update Beacon mount to work with older Rev D beacon probes 
* Added a new rear bowden entry set, supporting m10 collet, ECAS collet, or No collet 
* Added R1 style stock panel clips (tool less panel clips are coming soon as an option as well)
* Added fixed Z belt covers to better fit with the R1 Z belt location
* Organized the panel file directory 

### 7-15-2024
* Added Beacon probe mount

### 7-08-2024
* Added 120x120 build R1 Cad assembly
* Added rear skirts for 120x120 builds 
* Organized files into 120 and 180 specific folders 

### 7-05-2024
* added rear power inlet skirts
* updated printed rail stops to match the style of R1 update (low poly look)
* added keystone blank model to fill the keystone slots on the rear skirt if not used 

### 7-02-2024
* updated Z drive tensioner body to use longer m3x25 instead of m3x20
* added optional Hula feet adapters for R1 and G2Z
* updated latest cad assembly

### 6-18-2024
* uploaded side skirts and 4.3 waveshare display front skirt

### 6-2-2024
* changed hex pattern on Z drives to make them easier to print 

### 5-21-2024
* adjust the location of the Z gantry belts pulley to fit in the front idlers better ([#124](https://github.com/PrintersForAnts/Micron/issues/124))

### 5-14-2024
* fixed z drive issue with inconsistencies with both A and B z drives ([#120](https://github.com/PrintersForAnts/Micron/issues/120))
* updated z tensioner bearing overhang to be easier to print ([#122](https://github.com/PrintersForAnts/Micron/issues/122))

### 5-7-2024
* Added ziptie spot on to klicky dock

### 5-6-2024
 * Updated Z drives to fit powge and formbot metal 64T pulleys ([#115](https://github.com/PrintersForAnts/Micron/issues/115))
 * Updated Z idlers to fit toothed pulleys with a flange of 13mm OD ([#116](https://github.com/PrintersForAnts/Micron/issues/116))
 * raised klicky dock , it was hanging too low ([#117](https://github.com/PrintersForAnts/Micron/issues/117))
 * updated spool holder to now work with 3mm foam ([#118](https://github.com/PrintersForAnts/Micron/issues/118))

### 4-6-2024
 * added pushed rigid z joints
 * new z belt covers
 * new bowden tube holder
 * new removable spool holder (modified from LDOs)

### 4-5-2024
  *  Added Nema14 Z motor mounts

### 4-3-2024
  * New beta rev2 Z drives with the 152mm belt loops
  * Shrunk entire body by 5mm or so
  * rotated the Z drives 180deg, this makes it easier to retention the closed loop belts after they are assembled if needed (thanks [@Squirrel-brain](https://github.com/Squirrel-brain)) 

## BOM Changes (Subject to change)
Item  |Qty | Notes
 ----|----|----|
GT2-16-Toothed Idler | 6 | XY-Joints and Z idlers now use toothed idlers by default, bearing stacks will still work 
GT2-152mm closed loop belt | 4 | New Z drives use 152mm belt loops instead of the 188mm 
screws | IDK | i havent gone through and checked the changes for the hardware as of yet 
MGN9H | 1 | X rail is now going to be spec as an MGN9H rail instead of MGN9C to support boop natively 
Klicky_PCB | 1 | now offical support optional as standard klikcy is still supported 
BIQU_microprobe | 1 | also now an official supported mount for those that want to use it

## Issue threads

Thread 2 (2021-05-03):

Z idler needs mod to use standard-size screw

zruncho3d, 2021-05-03:
The Z idler body is 18.5mm thick.

With a 20mm screw, you can't get thread engagement on an M3 nut.   With a 25mm screw, you can't fit the screw in the slot in the extrusion.

Either it needs to be thicker (say, 2mm) or have a little counterbore (say, 2mm).  See pic:

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

Closed 2021-06-14.

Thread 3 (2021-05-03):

Z belt path interferes with lowermost side frame rail

zruncho3d, 2021-05-03:
On v9 of Micron2.4, the Z belt path goes within the bounds of the frame near the outer edge.

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

So either the belt needs to be adjusted inwards, and the AB idlers adjusted to match (by ~2-3mm), with the motor kept below the frame...

--OR---

If going direct drive, the motor might "live within the bounds of the frame".

Check this pic, which shows a a 35mm-wide NEMA14 inside the frame.  Imagine this on the inside of the frame, towards the right center.    The pic also shows the bounding box for the 53mm-wide new MiniAB toolhead.  There's ~1mm of clearance as-is, so nothing actually needs to change.  I think this is the way to go to test things out (keeping the AB idler).  It's much more efficient packaging; otherwise that space is wasted.

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

The motor would be pointed from the center towards the carriage.  So two would be mounted, butt pointing to butt.  One is shown in this pic.

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

Yet what about clearing the bottom of the gantry?  Fate... there's clearance already, ~2.5mm or so!  There's space already, because the bottom-hanging AB drives need clearance.   And there's just enough space to clear those AB drives too, though it'll be tight.

I'm honestly tempted to build a side with the existing parts and just clamp a motor in the position shown, because the mount would be the dumbest, simplest thing every - just an L bracket with holes, to attach to an extrusion.

-------

Separately - you could also change where the Z belt goes through the AB idler, from the inner side of the AB belt idler towards the outer side, and that could give space for a NEMA17 too (needs an extra 3.5mm of motion, since 7mm wider).  That motor wouldn't stick out more than the MGN7 carriage already does.  So that seems like a good option too.  If this was done anyway, you could fit both motor types in easily.

Thoughts on any of these?

Closed 2021-05-23.

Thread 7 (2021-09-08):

Modify z_drive_base_plate to reduce BOM

Finn2708, 2021-09-08:
Replace M3x6 SHCS with M3x8 SHCS to reduce BOM.

Only a minor adjustment on the `z_drive_base_plate` is required.

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

Closed 2021-09-08.

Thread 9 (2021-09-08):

Add missing screws to front idlers and fix length/naming

Finn2708, 2021-09-08:
Some screws seem to be missing.

Some are called M3x8 but are actually 12mm.
Some are called M3x12 but are actually 14mm.

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

Closed 2021-09-08.

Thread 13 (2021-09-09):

Main CAD needs shorter endstop

grmocg, 2021-09-09:
A potential take on this is already in: Micron/CAD/z_probe_endstop/z_nozzle_endstop_short.STEP

grmocg, 2021-09-17:
Done with commit 0b9a25d64bb0c09e96acf30cd9f1b025881ac5d1

Closed 2021-09-17.

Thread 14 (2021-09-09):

Main cad needs 60mm fan mount integrated

grmocg, 2021-09-09:
Fan mount piece is at: cad/skirt/60mm_fan_mount.STEP
There will need to be two, mirrored.

Also need to add the 60mm fan.

Closed 2021-09-15.

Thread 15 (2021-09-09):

Align headset insert in all Z Drives

Finn2708, 2021-09-09:
-This serves as a reminder to myself-

Already fixed here:
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

hartk1213, 2021-09-09:
awesome, also i just realized there is a heatset and an m3 in the z drive cap for the rubber foot...those can also be removed since they are now m5 and hex nut

Finn2708, 2021-09-09:
Alright, I will remove them.
Those were not in the BOM anyway.

Closed 2021-09-09.

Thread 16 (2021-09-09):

Push new bed screws

Finn2708, 2021-09-09:
-This serves as a reminder to myself-

Bed Screws: M3x14 instead of M3x16 (those will collide with the extrusion)

Closed 2021-09-09.

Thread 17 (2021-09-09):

Swap motor screws

Finn2708, 2021-09-09:
-This serves as a reminder to myself-

Replace M3x12 SHCS with M3x10 BHCS.

Stepper motor does not have 6mm thread. BHCS because there are no M3x10 SHCS in the BOM.

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

Finn2708, 2021-09-09:
M3x8 for mounting to the frame

Closed 2021-09-09.

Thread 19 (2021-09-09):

Fix counterbores of X Carriage

Finn2708, 2021-09-09:
X Carriage does not work IMHO in current configuration.

I would like to keep M3x8 BHCSs, so decreasing the depth of the counterbore would be the way to go. Alternatively M3x6 BHCS which would be lighter but are not in the BOM yet...

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

Closed 2021-09-09.

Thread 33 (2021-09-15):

Provide more clearance for USB-C for spider in flat mount.

grmocg, 2021-09-15:

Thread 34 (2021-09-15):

need SSR mount for AC-bed configuration

grmocg, 2021-09-15:
I'm thinking to modify the rear skirt to provide for a cap to the inlet anyway. That could include two variants: one for DC beds, and one for AC beds that has a mount for the BoM SSR.

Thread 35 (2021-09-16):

Motor cover STLs incompatible with longbois

grmocg, 2021-09-16:
We need to generate the STLs for the motor covers in the CAD, and the even-more-space variants.

grmocg, 2021-09-17:
Done with 0b9a25d64bb0c09e96acf30cd9f1b025881ac5d1

Closed 2021-09-17.

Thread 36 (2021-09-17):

Skirt trim and skirts have incorrect hole size for heat-inserts

grmocg, 2021-09-17:
Currently these holes are 4.5mm. They should be 4.7mm

grmocg, 2021-09-27:
side skirts fixed with 5c98d4c

grmocg, 2021-09-27:
f/r with 142173effffd7953578c6cdbb2ef67985eaa38af

Closed 2021-09-27.

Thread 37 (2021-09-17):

Move PI back in the electronics mounting so the hinge can work in both ways

grmocg, 2021-09-17:
It is possible to make it so we can hinge the electronics with the deck panel (like a car trunk), and not just hinge down/out as it does now.

Making this a possibility requires moving the Pi's mounting so that there is sufficient clearance.

grmocg, 2021-09-18:
Wouldn't be a terribly useful thing, so not worth fixing.

Closed 2021-09-18.

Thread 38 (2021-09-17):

stacked electronics mount allows octopus to touch motors when placed upside down

grmocg, 2021-09-17:
Ideally that won't happen.
Looks like the slots for the hinge are longer than they need to be for freely hinging the assembly. Thus, one possible solution is to make that smaller.
Another solution is to have a nub sticking out from the edges that would touch the motor before the PCB of the octopus would.

grmocg, 2021-09-17:
When the Micron is right-side-up, this isn't a problem.

Another solution is to have the mount push against the frame when it is locked in, which might require another preloaded nut.

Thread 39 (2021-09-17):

make side-skirts have same mounting stuff as the f/r skirts.

grmocg, 2021-09-17:
f/r skirts have a keyhole-based mounting. Normalize the side-skirts with this and ensure mounting depth is the same.

grmocg, 2021-09-27:
Fixed with 5c98d4c

Closed 2021-09-27.

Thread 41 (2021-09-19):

panzer chains missing top clip

grmocg, 2021-09-19:
https://github.com/VoronDesign/VoronUsers/blob/master/printer_mods/Slidr/PanzerChain2.4/stl/xyz_clip.stl

grmocg, 2021-09-29:
fixed by hartk

Closed 2021-09-29.

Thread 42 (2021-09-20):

Panzerchain z_anchor_frame is non-functional

grmocg, 2021-09-20:
Looks like the support is offset relative to the z_anchor frame.

grmocg, 2021-09-29:
fixed by hartk

Closed 2021-09-29.

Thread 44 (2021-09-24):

Toolhead hits klicky dock

moodytechz, 2021-09-24:
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

I think the dock arm will need to be drop down a bit. Roughly 5.5mm. The blower housing crashes into it before hitting the endstop.

Closed 2022-04-01.

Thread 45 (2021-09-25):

M2 Nut adapter STL missing

Finn2708, 2021-09-25:
This seems to be missing in the repo:
https://github.com/VoronDesign/Voron-0/blob/Voron0.1/STLs/M2_Nut_Adapter_Rotated_x5.stl

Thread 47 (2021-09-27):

[a]_z_anchor_gantry_x1.stl orientation is wrong

Finn2708, 2021-09-27:

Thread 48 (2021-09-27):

Ensure that 60t gears can be used

grmocg, 2021-09-27:
Ensure that 60t gears can be used-- this will involve providing more clearance for the motor-mounts<->skirt (at least 4mm), and probably rounding the edges of the motor.

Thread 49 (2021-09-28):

Missing STL's from folder:  Micron/STLs/Gantry/Toolhead/

moodytechz, 2021-09-28:
https://github.com/VoronDesign/Voron-0/blob/Voron0.1/STLs/Toolheads/Mini_Afterburner/Guidler_DD_x1.stl
https://github.com/VoronDesign/Voron-0/blob/Voron0.1/STLs/Toolheads/Mini_Afterburner/Latch_DD_x1.stl
https://github.com/VoronDesign/Voron-0/blob/Voron0.1/STLs/Toolheads/Mini_Afterburner/Latch_Shuttle_DD_x1.stl
https://github.com/VoronDesign/Voron-0/blob/Voron0.1/STLs/Toolheads/Mini_Afterburner/Motor_Frame_x1.stl
https://github.com/VoronDesign/Voron-0/blob/Voron0.1/STLs/Toolheads/Mini_Afterburner/Strain_Relief_Body_x1.STL
https://github.com/VoronDesign/Voron-0/blob/Voron0.1/STLs/Toolheads/Mini_Afterburner/Strain_Relief_Spacers_x2.STL

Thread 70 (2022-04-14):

Minimun layer height?

ManuelPeiro, 2022-04-14:
Hi,

What its the minimun layer height I can reach with this printer? I am interested in one printer for layer 0,05 mm or less.. I dont like DLP...

rufinus, 2023-03-30:
this will more depend on the nozzle size you will use. the steppers should have a minimum step around .0025 mm

Closed 2023-05-27.

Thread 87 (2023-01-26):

Spacing bed extrusions for 180 size is not mentioned

Toogo, 2023-01-26:
spacing is for 120 size, where there is also a 180 version.

hartk1213, 2023-06-21:
i have uploaded the work in progress manual that now goes over both 120 and 180 frame assembly
https://github.com/PrintersForAnts/Micron/blob/main/Documentation/Micron_Manual_WIP-6-20-23.pdf

Closed 2023-06-21.

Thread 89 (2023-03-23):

Revised A drive upper missing extrusion indexing tabs

Outrider305, 2023-03-23:
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

Opening git issue as requested on discord. Three of the four A drive upper pieces are missing the extrusion indexing tabs for both the CAD and individual STLs.

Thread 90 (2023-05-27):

Cannot open the assembly step file in Solidworks

Blue-RR, 2023-05-27:
The "Micron_CAD_Assembly_gantry_update_5-12-23" step file contained within the "Micron-hartk_gantry_fix" branch CAD folder cannot be open in Solidworks. The following error is shown:

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

Blue-RR, 2023-08-22:
This can be closed, the latest release seems to be fine in Solidworks.

Closed 2023-08-22.

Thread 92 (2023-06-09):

Missing some STL's for Stealthburner

DaveyRance, 2023-06-09:
The following STL's seem to be missing for a complete Mini Stealthburner.

https://github.com/VoronDesign/Voron-0/blob/Voron0.2/STLs/Toolheads/Mini_Stealthburner/%5Ba%5D_MiniSB_Motor_Plate_x1.stl
https://github.com/VoronDesign/Voron-0/blob/Voron0.2/STLs/Toolheads/Mini_Stealthburner/Strain_Relief_Spacer_x2.stl
https://github.com/VoronDesign/Voron-0/blob/Voron0.2/STLs/Toolheads/Mini_Stealthburner/Strain_Relief_Body_x1.stl
https://github.com/VoronDesign/Voron-0/blob/Voron0.2/STLs/Toolheads/Mini_Stealthburner/%5Ba%5D_Guidler_x1.stl
https://github.com/VoronDesign/Voron-0/blob/Voron0.2/STLs/Toolheads/Mini_Stealthburner/%5Ba%5D_Latch_x1.stl
https://github.com/VoronDesign/Voron-0/blob/Voron0.2/STLs/Toolheads/Mini_Stealthburner/%5Ba%5D_Shuttle_x1.stl
https://github.com/VoronDesign/Voron-0/blob/Voron0.2/STLs/Toolheads/Mini_Stealthburner/%5Ba%5D_MiniSB_MidBody_x1.stl

This seems to be a repeat of the issue
https://github.com/PrintersForAnts/Micron/issues/49

hartk1213, 2023-06-20:
Yeah I can get those added soon, I was waiting for v0.2r1 to get released 👍

KyleEgan, 2023-08-11:
This was resolved with the R1 MiniSB files 👍🏻

DaveyRance, 2023-08-12:
Looks good. Was there a changelog for what changed with MiniSB R1 as my searching is failing me. (want to figure is it worth re-printing)

DaveyRance, 2023-08-12:
Incase anyone else is looking from the v0.2R1 Release notes

Toolhead
Mini Stealthburner direct drive and bowden cowling part cooling ducts improved
an issue with the guidler being able to pivot in an undesired direction was addressed by tightening the bolt holes to reduce play
RIDGA support for the bearings that come stock with the ridga kit has been added

Closed 2023-08-12.

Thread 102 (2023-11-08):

220mm_m2_nut_adapter_rotated_x6(MICRON+).stl has incorrect orientation by default

dderg, 2023-11-08:
I believe it would print better if you flip it upside down

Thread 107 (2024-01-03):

KGLM-03 adaptation issues

LeoD218, 2024-01-03:
KGLM-03 is too expensive and difficult to buy, can it be adapted to other bearings?

grmocg, 2024-01-03:
There is already a non-KGLM-03 option:
 [[a]_z_joint_printed_alternative_x4.stl](https://github.com/PrintersForAnts/Micron/blob/main/STLs/Gantry/Z_Joints/%5Ba%5D_z_joint_printed_alternative_x4.stl)

hartk1213, 2024-04-05:
> KGLM-03 is too expensive and difficult to buy, can it be adapted to other bearings?

As stated above there is a printed only option.. going to close this issue

Closed 2024-04-05.

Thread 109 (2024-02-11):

Direct access to Micron_CAD_Assembly.step instead of zip file

izanamisu, 2024-02-11:
Hi,

We are using an addon for fusion360 called Voron-Construct ( https://github.com/PrintersForAnts/Voron-Construct)
The addon gives us acces to step files to use in fusion.

The printer files are ziped and are not available in the addon, can you guys unzip and upload the step files to the cad repositories?

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

izanamisu, 2024-02-11:
PS, Tiny-t and others as well please.

izanamisu, 2024-02-11:
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

hartk1213, 2024-03-25:
not at the moment, it becomes too big of a file at that point , R1 cad is unzipped tho

ill have to fix the cad file to make it smaller but that most likely wont be until R1 is done

THEDUDEDAD, 2024-04-05:
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

Do you recommend a new builder with a forbot micron kit, to do the r1 gantry or stock ?

hartk1213, 2024-04-05:
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

R1 at this point

Closed 2024-04-24.

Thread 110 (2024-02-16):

Gap between the "in part" support and the part itself is too wide on the 2 legs.

BelgarionNL, 2024-02-16:
X_Carriage_MGN9H_Micron_Long.stl

TheyCallMeZ, 2024-04-05:
Hi @BelgarionNL This file doesn't seem to be part of the Micron repo. I don't think anyone here will be able to assist you with it. Sorry about that.

Closed 2024-04-24.

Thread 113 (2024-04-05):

Only `z_tensioner_a` inclunded in repo STLs

DonutCables, 2024-04-05:
In the CAD there's `z_tensioner_a` to accompany `z_tensioner_bracket_a`, and likewise for B, but `STLs/Z_Idlers/[a]_z_tensioner_x4.stl` is only the A variant, so unless you know to mirror two of them for printing you have to assemble them opposite of the manual or have slop in the bearings from the screw not tightening properly.

TheyCallMeZ, 2024-04-05:
Hi @DonutCables I double checked in my slicer and the tensioner piece is universal.  Using some clever rotation I can demonstrate this
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

That said I know many people including myself have gone with the [Beefy Z Idlers by clee](https://github.com/clee/VoronBFI/tree/main/STLs/BZI)

DonutCables, 2024-04-05:
The problem isn't whether they'll fit the other pieces, the issue is one of the screw holes is 3mm to be threaded into and the other is 3.4mm for a through-fit. So when it's four printed the same direction you have to ignore the info in the guide and put two screws for the bearings opposite direction to actually close the piece into the bearings.
And while people may use those files, they're not the most helpful for us getting PIF prints.

TheyCallMeZ, 2024-04-05:
@DonutCables you are correct. I went ahead and mirrored the stl and fixed the naming, I have also created a PR into the main repo branch.

I have printed it and the image showing the test fit is on the pull request.

hartk1213, 2024-04-05:
> The problem isn't whether they'll fit the other pieces, the issue is one of the screw holes is 3mm to be threaded into and the other is 3.4mm for a through-fit. So when it's four printed the same direction you have to ignore the info in the guide and put two screws for the bearings opposite direction to actually close the piece into the bearings. And while people may use those files, they're not the most helpful for us getting PIF prints.

Pif doesn't supply micron files , also R1 micron has better Z idlers that should be used now anyway

hartk1213, 2024-04-05:
> Hi @DonutCables I double checked in my slicer and the tensioner piece is universal. Using some clever rotation I can demonstrate this ![image](https://private-user-images.githubusercontent.com/321143/319991824-3e411f8e-c784-43c8-9e25-ca62b08cf70e.png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)
>
> That said I know many people including myself have gone with the [Beefy Z Idlers by clee](https://github.com/clee/VoronBFI/tree/main/STLs/BZI)

The files in clees repo need to be updated..R1 has newer BZI files

Closed 2024-04-19.

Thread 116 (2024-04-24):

Z idlers dont fit bigger 16T idler pulleys

hartk1213, 2024-04-24:
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
dont fit the 13mm OD pulleys , they rub on the printed part

hartk1213, 2024-05-06:
fixed with https://github.com/PrintersForAnts/Micron/commit/d570fa8b737f0f519dd8379f9a187f71221e1273

Closed 2024-05-06.

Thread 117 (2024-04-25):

R1 Klicky dock is a bit too low

rsletten, 2024-04-25:
Using

[R1 Gantry Dock](https://github.com/PrintersForAnts/Micron/blob/main/R1_Beta/STLs/Gantry/%5Ba%5D_klicky_gantry_dock.stl)
[Dock](https://github.com/tanaes/whopping_Voron_mods/blob/main/pcb_klicky/STLs/dock-front_insert.stl)
[Probe for Dock](https://github.com/tanaes/whopping_Voron_mods/blob/main/pcb_klicky/STLs/probe-heatset.stl)
[X Carriage](https://github.com/chirpy2605/voron/blob/main/general/Alternative_Voron_Mounts/Modified_Mounts/Micron_Pandora/STLs/X_Carriage_MGN9H_Micron_Long.stl)
[X Carriage Klicky PCB mount](https://github.com/PrintersForAnts/Micron/blob/main/R1_Beta/STLs/Gantry/X_Axis/Probes/klicky_probe_pcb_mount_x1.stl)

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

hartk1213, 2024-05-06:
fixed with https://github.com/PrintersForAnts/Micron/commit/d570fa8b737f0f519dd8379f9a187f71221e1273

hartk1213, 2024-05-07:
> @hartk1213 not sure if you get notifications from closed issues ^

added to the latest files  👍🏻
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

Closed 2024-05-06.

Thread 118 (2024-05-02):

New R1 spool holder foam #R1_beta_issues

LordKillZone, 2024-05-02:
I think R1 new spoolholder is for 1mm foam, i am using 3mm foam and cannot fit this new spoolholder to mine micron.

LordKillZone, 2024-05-06:
[
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
](url)

hartk1213, 2024-05-06:
fixed with https://github.com/PrintersForAnts/Micron/commit/d570fa8b737f0f519dd8379f9a187f71221e1273

Closed 2024-05-06.

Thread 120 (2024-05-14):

(R1 beta) Z-Drive Main Body A/B STLs are inconsistent with respect to the shaft cutout

skuep, 2024-05-14:
See this image for clarification

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

The same problem with the mating side (Shaft Assembly Covers), both of them actually.

As mentioned on discord, it might be worthwhile to enlarge the clearance to allow 60mm shaft length.

Closed 2024-05-14.

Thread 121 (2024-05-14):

(R1 Beta) Enhancement/Fix XY joints cad the holes need adjustment for pin & add recesses for MR63-RS bearings

shawnchr, 2024-05-14:
The plastic tweaks when fully tightened with pin inserted in the toothed pulley spot.
If you could make that version accept MR63-RS 3mm ID x 6mm OD x 2.5mm thick bearings could use a live shaft setup and get away from the awful bearing in the toothed pulleys this would be much better option.

hartk1213, 2024-05-14:
which toothed pulleys would you want to use on those live shafts? screenshots, images, etc.. would be helpful
i have looked into this many times and its pretty tight spacing

shawnchr, 2024-05-14:
https://www.aliexpress.us/item/3256806492847474.html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￼
0.99US $ 84% OFF|5pcs/lot, H Type 2GT Timing Pulley for 6mm Wide Belt 16 20 Teeth 3mm 4mm 5mm Bore with Screw Hole| |
aliexpress.us

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

hartk1213, 2024-05-17:
CAD is available and at this time I don't plan on making this change

Closed 2024-05-17.

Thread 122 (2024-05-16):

(R1 Beta) Issues/Suggestions on Belt Tensioning Mechanism

skuep, 2024-05-16:
- There was one minor issue with the motor mount, where there is an unprintable overhang. Probably something a chamfer can already fix.
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

- In my setup (152mm Belt, 16T pulley and 64T POWGE Pulley) this picture represents a pretty tight tensioned belt already. The M3x12 screw tensioning screw only grabs half a turn at this point. I needed to change it for a M3x16. Is this by design? I think this particular thing is also misaligned in the CAD.
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

- It might also be worthwhile, to widen the slot so that we can use a regular DIN125 size washer below those two fixation screws. Otherwise the slot gets mangled up pretty fast by those small screw heads.

- Is it possible to integrate a window into one of the sides of the mechanism to see if the motor pulley height is aligned correctly? Maybe even to better check the belt tension than by poking in an allen key from the top at an angle to see the belt tension. Maybe on the side facing downwards?

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

hartk1213, 2024-05-21:
Issue 1 , heatset holes now chamfered
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

Issue 2a, slots now big enough to accept m3 washers 7mm OD, .5mm thick same washers used in other locations of the build
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

Issue 2b, yeah good call changing that screw to m3x16 instead of m3x12, there is plenty of room for a 16SHCS there
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

issue 3, added small window to check belt alignment
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

ill get these changes exported to and pushed to the repo then ill close the issue

skuep, 2024-05-21:
Awesome, that looks really nice!

Closed 2024-05-21.

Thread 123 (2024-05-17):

(R1 Beta) 50mm Skirt Fan Option

Walmtech, 2024-05-17:
In the new skirt could an option for 50mm fans be provided as there is now enough room for them? (I guess 40mm would still be needed for people upgrading using the orginal BOM)

hartk1213, 2025-01-20:
not at this time , cad is available for mods 👍🏻

Closed 2025-01-20.

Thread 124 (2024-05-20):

(R1 Beta) Z drives belt alignment issues

skuep, 2024-05-20:
After installing the new Z drives In noticed that the belt is very close to the inside of the belt routing channels in the front idler and rear AB joints (and belt covers). See these photos:

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

The belt seems to be too close to the center of the printer on all 4 Z belts. In the Z-drive, the belt is actually very well centered in the slot of the 16T pulley. Its a bit hard to see here, but take my word for it.
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

I switched to CAD and took some measurements, and it seems like there is a difference in Z-belt position compared to the "old" (current) release that would totally explain these differences. See screenshot here, "old" on the left, R1 on the right. Measurement shows the distance from the front face of the front beam to a specific face on the 16T Z-pulley. There is roughly 1mm difference, which is basically what I observed.

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

hartk1213, 2024-05-21:
ok this was a few things, the gantry was misaligned in the main assembly but the belt was also off by about .5mm (.528mm) to be exact now its perfectly centered in the gantry spots (Idlers/AB Drives)
before
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
after
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
AB Drives as well
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

Ill close this with the next push to the repo

skuep, 2024-05-21:
Nice, thanks a lot! Did you change something in the Z drives with regards to belt alignment?

hartk1213, 2024-05-21:
Yes, I adjusted the location of the Z belt pulley to get the belts centered up where they should be

Closed 2024-05-21.

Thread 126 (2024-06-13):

(R1 Beta) Z Drive Main body A & B - Chamfer for locating tabs

cgauvrit, 2024-06-13:
R1 Z Drive Main body A & B - would benefit from the chamfer for locating tabs on the other side for printability
Latest STL from the repo was used.

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

hartk1213, 2024-06-19:
Ah good catch...the chamfer that is there is for that reason, they used to print on the other side but changed ..missed that 👍🏼

Closed 2024-07-02.

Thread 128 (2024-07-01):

(R1 Beta) Z A & B  Drives 20mm corner screws struggle to engage with brass inserts

Foofinator94, 2024-07-01:
The 2 off M3 x 20mm screws on  the corners of the Z drives have poor engagement with the brass inserts.

A combination of screw thread tolerance, printing tolerance of the clamped part height and counterbore overhangs, and brass insert geometry hamper engagement of the threads.

Suggest to either:

- Increase the counterbore depth to expose more threads to engage in the brass insert (~ 0.5-1mm suffice).
- Increase the bore depth of the brass insert hole to allow M3 x 25mm screws to be used instead of M3 x 20.

warasilapm, 2024-07-01:
+1 I also experienced this during my build this past weekend.

Closed 2024-07-02.

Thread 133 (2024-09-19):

Impossible to source the new belt spec in EU

testack18, 2024-09-19:
I have a brand new Formbot Micron+ kit. The new R1 specs mentions that we need 152mm belt but the Formbot kit still ships 188mm belt.

In the EU it is impossible to source genuine GATES belt with this spec. Even in 150mm length. It is also hard to find in stock for example in the US. Additionally if I find something in US just the shipping fee costs $90+ not included VAT.

This means from my perspective that this belt spec is something which is hard to source. While Voron philosophy as far as I know is meant to be something which does not contain hardly sourcable or special components. I know Micron is not an official Voron, but.... You understand my point, right?

Anyways, any recommendation where to source genuine GATES belt with specs? Or any other good quality alternative within EU? I have read that the cheap aliexpress belts contains in practice steel instead of fiber glass (no matter what they states on their sales page) which makes them easily breakable compared to RF GATES belts. So any hints what can we do outside the US? Where can we source this component at a reasonable cost?
Or just what happens if I keep using the 188mm belt come with the Formbot kit?

Any hits/advice would be really appreciated!

hartk1213, 2024-09-20:
@testack18 can you order from Ali Express? You can find them all over there...and for the closed loop belts I don't think getting official gates is as crucial as it is for the rest of the machine ..I've used non gates belts for those without issue

testack18, 2024-09-20:
Of course, I can. My concern with them is what I mentioned I have read about them. Their reinforcements is not fiberglass whatever they states, which causes shorter lifetime. They weares out much faster then genuine GATES. I think I don't have to explain what unriabilities thise can cause after a (not so long) while. How long have you used those non gates belts you mentioned?
If you could share a link you have ordered, I would really appreciate!

Ohh, and I forgot to thank your huge effort you have put into this printer's design hartk!

EllaFoxo, 2024-10-26:
Cutting down to size yourself should be viable if you buy per meter. [3DO](https://3do.dk/en/belts/279-original-gates-belts-gates-ll-2gt-price-per-meter.html) has it.

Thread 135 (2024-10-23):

Printed parts

astur35, 2024-10-23:
Good morning, I am starting to do this project because of the good bed size it has, better than the voron 0.2. My problem comes that I can not find anyone to print all the necessary parts, as they do not use nuts and with my resin printer I can not use inserts, I have to use nuts. Do you know anyone in Europe that prints these parts in ASA / ABS? Thank you very much for the great work done in the development of this machine.

Translated with DeepL.com (free version)

hartk1213, 2024-11-19:
i dont, but you could look for someone on the discord that might be able to help with that

Closed 2024-11-19.

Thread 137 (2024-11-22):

[R1 Beta] Built-in support is too close (in X/Y) to the TFT35 bezel

AlejandroRivera, 2024-11-22:
While printing the [TFT35 bezel](https://github.com/PrintersForAnts/Micron/blob/8ec208c5365e73786e8c0e066155aa44c8fbe698/R1_Beta/STLs/Skirts/Displays/TFT35/%5Ba%5D_bezel_x1.stl), I noticed that the clearance with the built-in support wasn't enough to prevent the pieces from being fused together (at least in a Prusa MK4S printing in with PLA using Voron settings).

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

The support was so fused it had to be cut with a exacto knife. Here's a picture of the result to give you an idea of where the fused edges happened:
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

I'd recommend increasing the clearance from 0.2mm to 0.3mm

hartk1213, 2024-12-19:
ABS is the recommended filament to print these in, i havent tried it with PLA but with ABS it was no issue

AlejandroRivera, 2024-12-20:
Yup, i agree that ABS is recommended and perhaps it wouldn't have this issue, or if it did, it might not be as hard to break apart, however, like you said, looking into it for a future bug fix might still help others since the Voron materials guide does say (https://docs.vorondesign.com/materials.html#pla)

> [...] PLA is entirely acceptable for skirts and panel clips as they do not see the same high temperatures or forces.

hartk1213, 2025-01-20:
@AlejandroRivera looking in cad the gap is actually 0.4mm

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

hartk1213, 2025-01-20:
ah i see now, one is .4 the other is .2 ill get that fixed

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

AlejandroRivera, 2025-01-21:
Thanks!

Closed 2025-01-20.

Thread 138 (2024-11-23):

[R1 Beta] Beacon/Carto Brace has 0.804 degree tilt

Foofinator94, 2024-11-23:
Appears the Carto/beacon mount is tilted relative to the carriage and fans by 0.804 degree measured in CAD files.

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

This might cause issue with Beacon/Carto measurements if the mount aligns to the toolhead fans at an angle.

Closed 2025-01-20.

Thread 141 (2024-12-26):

[R1 Beta] heatsets in fan skirts pull out easily and some fans require washers for use

Drift-68, 2024-12-26:
The fan skirts have an issue where the heat set inserts that the fan mounts to pull out too easily because of the way the holes are designed (being split between 2 parts) and fans that are countersunk (I hope that's the proper term) for screw heads sometimes need washers or something else in place to prevent the heat set from pulling directly out from the part into the space for the screw head when tightening screws.

The design could probably be tweaked by making the insert holes a bit smaller or making them only go through a single part to improve strength and adding files for gap fillers that press fit into the screw holes of "countersunk" fans making them a constant inner diameter would be helpful because getting washers in the right places is a pain. That said, I think just redesigning the way the fans mount would be best.

also I do want to add that these were the only parts on the entire printer I had these issues with, just to rule out bad tolerancing/filament.

thanks for reading my ramblings! Hopefully they are helpful -Drift

hartk1213, 2024-12-26:
i can look into making the holes smaller...the reason they are a 2 piece design is to hold the fan grills on to the skirts with out any hardware showing

Closed 2025-01-20.

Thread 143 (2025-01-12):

Missing nuts in R1 CAD for Z drives

hartk1213, 2025-01-12:

Closed 2025-01-20.

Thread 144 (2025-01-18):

Beacon/ Carto Mount for HF & UHF

chris155hp, 2025-01-18:
Requesting a Beacon Mount for HF and UHF

3DCreationsByChad, 2025-01-18:
What toolhead are you using?

chris155hp, 2025-01-18:
Anthead Sent from my iPhoneOn Jan 18, 2025, at 12:26 PM, 3DCreationsByChad ***@***.***> wrote:
What toolhead are you using?

—Reply to this email directly, view it on GitHub, or unsubscribe.You are receiving this because you authored the thread.Message ID: ***@***.***>

3DCreationsByChad, 2025-01-18:
Gotcha, I'm not sure if the mounting is the same. But I have a mount for rapidburner

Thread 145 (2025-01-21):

Incorrect tool STL orientation

rajenki, 2025-01-21:
https://github.com/PrintersForAnts/Micron/blob/main/STLs/Tools/x-rail-jig-x2.stl
https://github.com/PrintersForAnts/Micron/blob/main/STLs/Tools/y-rail-tool-180mm-x2.stl
https://github.com/PrintersForAnts/Micron/blob/main/STLs/Tools/z-rail-jig-x2.stl

STL orientation is incorrect on the above files.

Closed 2025-07-08.

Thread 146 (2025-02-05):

XY Joint live idler thin wall issue

hartk1213, 2025-02-05:
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

Closed 2025-10-07.

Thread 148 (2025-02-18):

R1 CAD issue - front tensioner screw incorrect

Foofinator94, 2025-02-18:
Current CAD has a 12mm BHCS on the front XY tensioners.

This can slip up and disengage with the tensioner:

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

This should be a 12mm SHCS on each side I believe to prevent this.

Closed 2025-03-03.

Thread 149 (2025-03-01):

R1 Issue - A drive bearing stack has 0 clearance and binds up

Foofinator94, 2025-03-01:
The single bearing stack on the rear has 0 clearance to the A drive parts.

When printed mine had noticeable drag and friction on this bearing vs the others.

The CAD has 0 clearance:

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

There should be clearance there.

It will wear out over time but the friction on mine meant the bearing was super hard to spin, even with the screw backed out. The other bearings have plenty of room.

Closed 2025-03-03.

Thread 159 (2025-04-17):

bed fans wire holes dont fit JST connectors - @hartk

hartk1213, 2025-04-17:
wire holes are too small for JST connectors to fit through

Closed 2025-04-17.

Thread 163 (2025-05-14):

AB motors in wrong orientation - @hartk

hartk1213, 2025-05-14:
Fix AB motor orientation in CAD

Closed 2025-05-29.

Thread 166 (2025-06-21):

Nut Adapters Upside Down?

smpanaro, 2025-06-21:
In the CAD it goes `nut | adapter | extrusion` (can see the whole nut from the bottom):

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

In discord it was [mentioned](https://discord.com/channels/825469421346226226/1103050453203308675/1124786180387524798) that it should be `adapter | nut | extrusion`. Since the manual doesn't show them sliding into the extrusion, I almost installed them upside down based on the CAD.

Closed 2025-07-08.

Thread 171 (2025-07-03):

test123

hartk1213, 2025-07-03:
test345

---
**Attached Images:**

> Error processing image from https://cdn.discordapp.com/attachments/1187117784438689842/1390462933494009937/FloroGreenMicron.png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: module 'PIL.Image' has no attribute 'ANTIALIAS'

> Error processing image from https://cdn.discordapp.com/attachments/1187117784438689842/1390462933779218513/FloroGreenMicronStripes.png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: module 'PIL.Image' has no attribute 'ANTIALIAS'

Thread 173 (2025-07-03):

test

hartk1213, 2025-07-03:
test

---
**Attached Images:**

![Image](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)

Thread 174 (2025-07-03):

test

hartk1213, 2025-07-03:
test

---
**Attached Images:**

> ⚠ Skipped image from https://cdn.discordapp.com/attachments/1187117784438689842/1390465168068055161/FloroGreenMicron.png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 (too large after compression: 70 KB)

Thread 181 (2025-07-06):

latest STLs don't match CAD, STLs are correct need to update

hartk1213, 2025-07-06:
latest STLs don't match CAD, STLs are correct need to update

<details>
<summary>Context from Discord</summary>

**Submitted by:** `hartk`
[View original Discord message](https://discord.com/channels/825469421346226226/1218239785932689478/1391292416367001601)

</details>

Closed 2025-07-08.

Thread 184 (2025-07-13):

A Drive Upper Pinned

hartk1213, 2025-07-13:
Pin holes in A Drive upper pinned variant are 3.4mm rather than 3.2mm.

<details>
<summary>Context from Discord</summary>

**Submitted by:** `kyle_gb`
[View original Discord message](https://discord.com/channels/825469421346226226/1173692825355944066/1394022083939536966)

</details>

M0rpheu5x, 2025-09-20:
https://canary.discord.com/channels/825469421346226226/1061793771169263726/1419104290039136306 I adjusted them to 3.2mm, can't upload a .stp to the comment though

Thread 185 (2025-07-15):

Manual z-drive shaft assembly flowchart has duplicates

Heptagon-1, 2025-07-15:
Occurs on page 61 (_BELTED Z DRIVES | Shaft assembly (continued)_). The component order on the shaft shown in the diagram is

1. 625 2RS bearing
2. M5x8 washer
3. 64T pulley
4. 16T Pulley
5. M5x8 washer x2
6. 625 2RS bearing.

In the flowchart, the 16T pulley and M5x8 x2 stages appear to be duplicated.

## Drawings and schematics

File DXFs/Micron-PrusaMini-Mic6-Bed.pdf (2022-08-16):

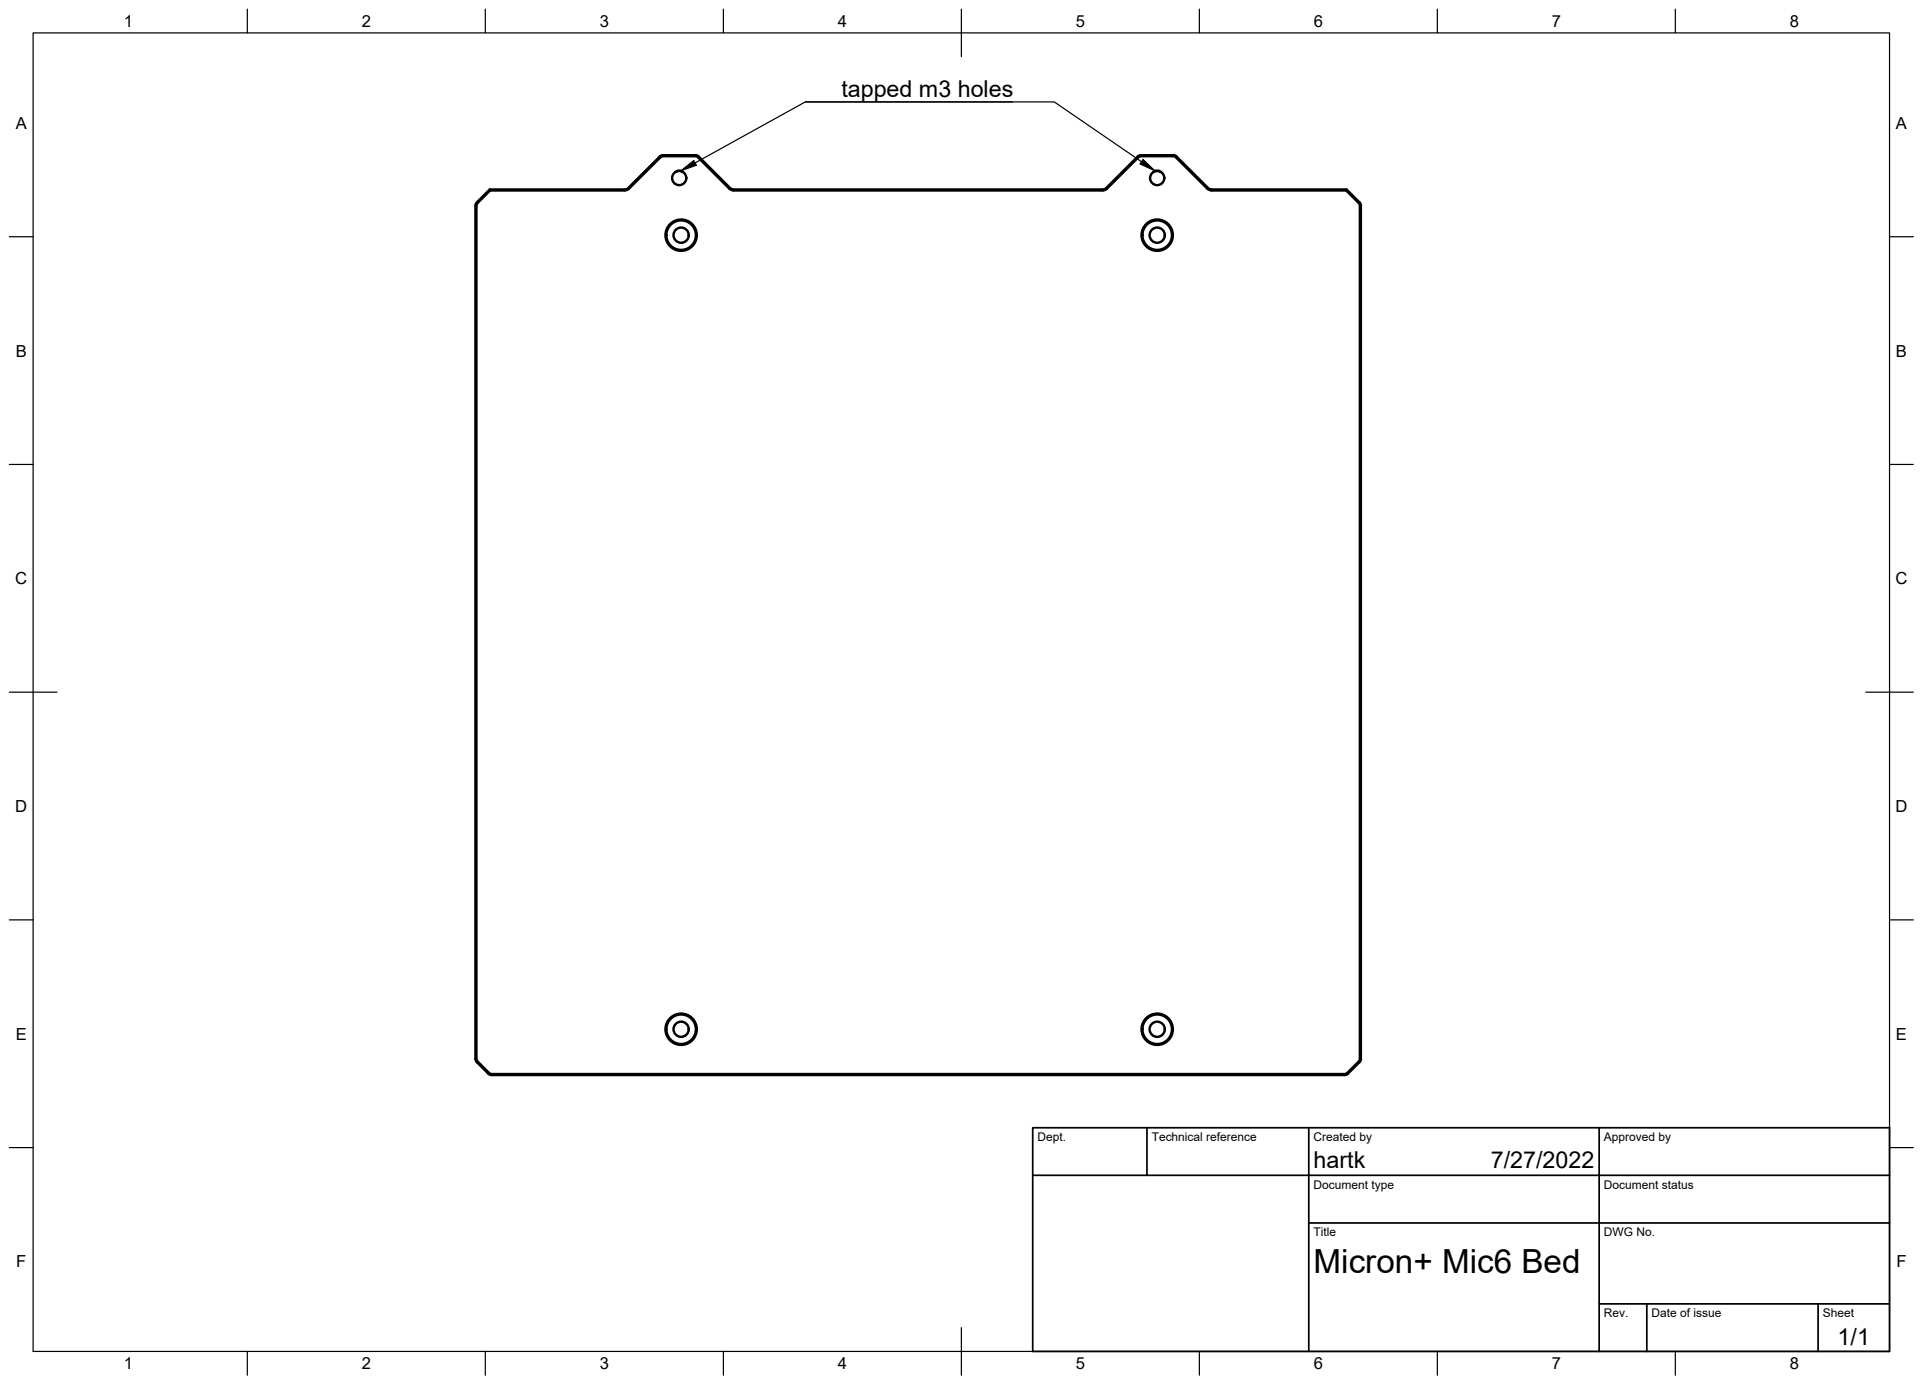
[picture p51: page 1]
Title; DWG No.; Rev.; Date of issue; Sheet; Micron+ Mic6 Bed; tapped m3 holes

Dept. | Technical reference | Created by hartk 7/27/2022 | Approved by

Document type | Document status

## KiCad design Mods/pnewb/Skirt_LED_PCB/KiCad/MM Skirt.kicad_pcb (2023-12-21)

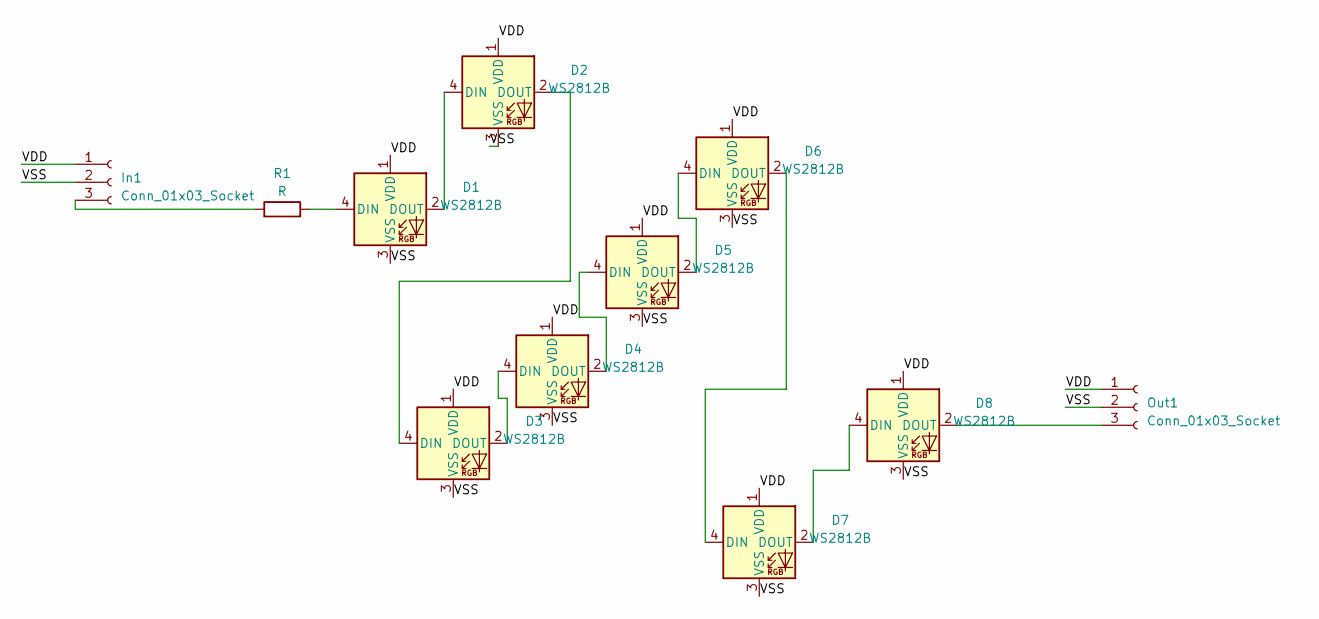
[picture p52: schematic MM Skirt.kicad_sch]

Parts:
D1, D2, D3, D4, D5, D6, D7, D8: WS2812B; LED_WS2812B_PLCC4_5.0x5.0mm_P3.2mm
In1: Conn_01x03_Socket; JST_XH_B3B-XH-A_1x03_P2.50mm_Vertical
Out1: Conn_01x03_Socket; JST_XH_B3B-XH-A_1x03_P2.50mm_Vertical
R1: R; R_1206_3216Metric

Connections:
/VDD: D1.1 (VDD), D2.1 (VDD), D3.1 (VDD), D4.1 (VDD), D5.1 (VDD), D6.1 (VDD), D7.1 (VDD), D8.1 (VDD), In1.1, Out1.1
/VSS: D1.3 (VSS), D2.3 (VSS), D3.3 (VSS), D4.3 (VSS), D5.3 (VSS), D6.3 (VSS), D7.3 (VSS), D8.3 (VSS), In1.2, Out1.2
unnamed: D1.4 (DIN), R1.2
unnamed: D1.2 (DOUT), D2.4 (DIN)
unnamed: D2.2 (DOUT), D3.4 (DIN)
unnamed: D3.2 (DOUT), D4.4 (DIN)
unnamed: D4.2 (DOUT), D5.4 (DIN)
unnamed: D5.2 (DOUT), D6.4 (DIN)
unnamed: D6.2 (DOUT), D7.4 (DIN)
unnamed: D7.2 (DOUT), D8.4 (DIN)
unnamed: D8.2 (DOUT), Out1.3
unnamed: In1.3, R1.1

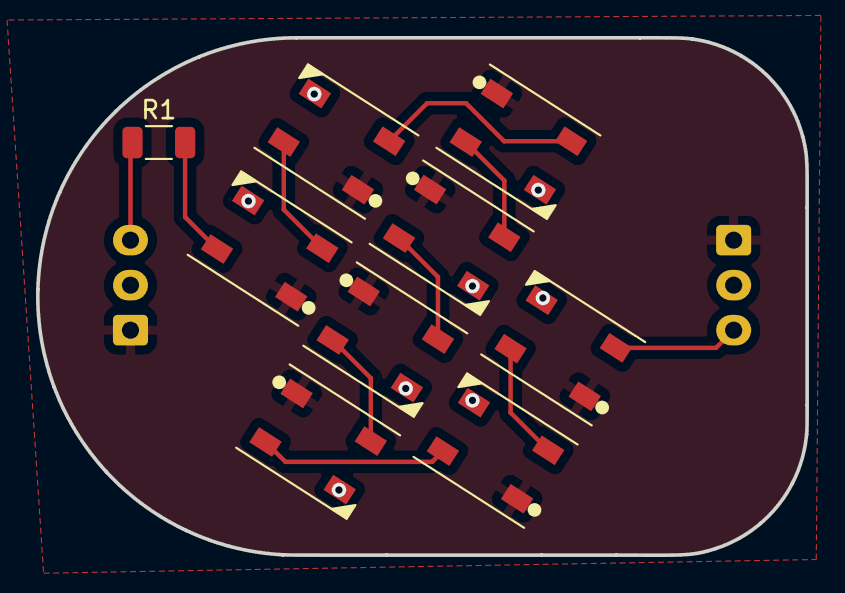
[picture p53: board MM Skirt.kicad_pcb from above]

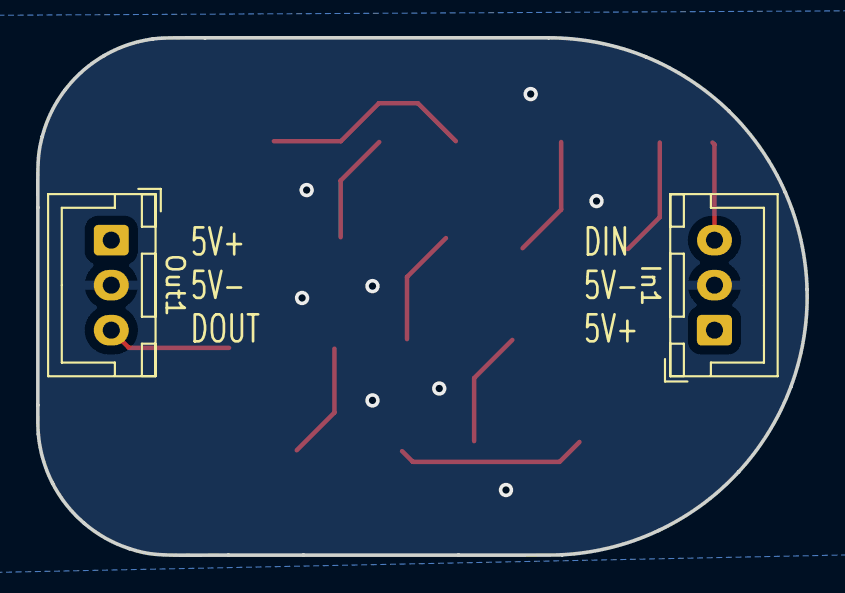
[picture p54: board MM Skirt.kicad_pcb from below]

Board: 2 copper layers, 42.7 x 28.7 mm, 11 parts (2 on the bottom side), 12 nets.

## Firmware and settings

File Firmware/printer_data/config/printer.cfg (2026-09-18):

#         +++++  ++++  XXXX       XXXXX  XXX    XXXXXXXXXX XXXXXXXXXX     XXXXXXXXXX    XXXX      XX
#        ++++  +++++   XXXXX     XXXXXX  XXX   XXX         XXX     XXX  xXXX      XXX  XXXXXX     XX
#       ++++  ++++     XXXXXX    XXXXXX  XXX   XX          XXX     XXX  XXX       XXX  XXXXXXX    XX
#     +++++++++++      XX  XXX  XXX XXX  XXX   XX          XXXXXXXXXX   XXX       XXX  XXXX XXXX  XX
#    +++++++++++++     XX  XXX XXX  XXX  XXX   XX          XXX  XXXX    XXX       XXX  XXXX   XXX XX
#  +++++               XX   XXXXX   XXX  XXX   XXX         XXX   XXXX   XXXX      XXX  XXXX    XXXXX
# +++++                XX    XXXX   XXX  XXX    XXXXXXXXXX XXX     XXX    XXXXXXXXXX   XXXX     XXXX


[mcu]
## For USB
##	Obtain definition by "ls /dev/serial/by-id/*" then unplug to verify
##--------------------------------------------------------------------
serial: /dev/serial/by-id/{REPLACE WITH YOUR SERIAL}
restart_method: command
##--------------------------------------------------------------------

## For CANBUS
##	Follow this guide to setup CANBUS
##  https://canbus.esoterical.online/
##--------------------------------------------------------------------
#canbus_uuid: 
##--------------------------------------------------------------------

## Toolhead Board
##--------------------------------------------------------------------
#[mcu thb]
## For USB
##	Obtain definition by "ls /dev/serial/by-id/*" then unplug to verify
#serial: /dev/serial/by-id/{REPLACE WITH YOUR SERIAL}
#restart_method: command

## For CANBUS
##	Follow this guide to setup CANBUS
##  https://canbus.esoterical.online/
##--------------------------------------------------------------------
#canbus_uuid: 
##--------------------------------------------------------------------

###########
# WEB GUI #
###########

# Mainsail 
#[include mainsail.cfg]

# Fluidd
#[include fluidd.cfg]

#######
# MCU #
#######

# LDO Leviathan
#[include LDOLeviathan.cfg]

# BTT Manta M8 V1.1
#[include BTTMantaM8P_v1-1.cfg]

# BTT Manta M8 V2
#[include BTTMantaM8P_v2.cfg]

##################
# Toolhead Board #
##################

# LDO NiteHawk36
#[include LDONH36.cfg]

# BTT EBB36
#[include BTTEBB36.cfg]

[printer]
kinematics: corexy
max_velocity: 200  
max_accel: 5000    			#This can be adjusted after you run Input Shaper calibration
max_z_velocity: 25 			
max_z_accel: 350
square_corner_velocity: 5

#######################
# Temperature Sensors #
#######################

[temperature_sensor MCU]
sensor_type: temperature_mcu

[temperature_sensor SoC]
sensor_type: temperature_host

[temperature_sensor THB]
sensor_type: temperature_mcu
sensor_mcu: thb
min_temp: 0
max_temp: 100

################
# X/Y Steppers #
################

## X Stepper on Motor1(B Motor)
[stepper_x]
step_pin: X_STEP
dir_pin: !X_DIR
enable_pin: !X_EN
rotation_distance: 32
microsteps: 32
full_steps_per_rotation:200 #400 for 0.9 deg steppers 
position_min: 0
homing_positive_dir: true
homing_speed: 60   
##  Uncomment if using endstop switches
#endstop_pin: ^thb:X_ENDSTOP
#homing_retract_dist: 5

##--------------------------------------------------------------------

##  Uncomment for 120 build
#position_endstop: 113
#position_max: 113

##  Uncomment for 180 build
#position_endstop: 173
#position_max: 173

##--------------------------------------------------------------------

##########################
#	Uncomment for Manta M8 #
##########################

#[tmc2209 stepper_x]
#uart_pin: X_UART
#interpolate: True
#run_current: 0.8
#sense_resistor: 0.110

##  Uncomment if using sensorless homing
#[stepper_x]
#endstop_pin: tmc2209_stepper_x:virtual_endstop
#homing_retract_dist: 0
#[tmc2209 stepper_x]
#diag_pin: ^MCU_STOP_X_ENDSTOP
#driver_SGTHRS: 255 # start at 255 (max sensitivity), use SET_TMC_FIELD to change at runtime


###########################
#	Uncomment for Leviathan #
###########################

#[tmc5160 stepper_x]
#cs_pin: X_CS
#spi_bus: spi4
#interpolate: false
#run_current: 0.8
#sense_resistor: 0.075

##  Uncomment if using sensorless homing
#[stepper_x]
#endstop_pin: tmc5160_stepper_x:virtual_endstop
#homing_retract_dist: 0
#[tmc5160 stepper_x]
#diag0_pin: ^!X_DIAG
#driver_SGT: 1


## Y Stepper on Motor2 (A Motor)
[stepper_y]
step_pin: Y_STEP
dir_pin: !Y_DIR
enable_pin: !Y_EN
rotation_distance: 32
microsteps: 32
full_steps_per_rotation:200 #400 for 0.9 deg steppers 
position_min: 0
homing_positive_dir: true
homing_speed: 60  
##  Uncomment if using endstop switches
#endstop_pin: ^MCU_STOP_Y_ENDSTOP
#homing_retract_dist: 5

##--------------------------------------------------------------------

##  Uncomment for 120 build
#position_endstop: 130
#position_max: 130

##  Uncomment for 180 build
#position_endstop: 190
#position_max: 190

##--------------------------------------------------------------------

##########################
#	Uncomment for Manta M8 #
##########################

#[tmc2209 stepper_y]
#uart_pin: Y_UART
#interpolate: True
#run_current: 0.8
#sense_resistor: 0.110

##  Uncomment if using sensorless homing
#[stepper_y]
#endstop_pin: tmc2209_stepper_y:virtual_endstop
#homing_retract_dist: 0
#[tmc2209 stepper_y]
#diag_pin: ^MCU_STOP_Y_ENDSTOP
#driver_SGTHRS: 255 # start at 255 (max sensitivity), use SET_TMC_FIELD to change at runtime


###########################
#	Uncomment for Leviathan #
###########################

#[tmc5160 stepper_y]
#cs_pin: Y_CS
#spi_bus: spi4
#interpolate: false
#run_current: 0.8
#sense_resistor: 0.075

##  Uncomment if using sensorless homing
#[stepper_y]
#endstop_pin: tmc5160_stepper_y:virtual_endstop
#homing_retract_dist: 0
#[tmc5160 stepper_y]
#diag0_pin: ^!Y_DIAG
#driver_SGT: 1


##############
# Z Steppers #
##############

## Z0 Stepper - Front Left 
[stepper_z]
step_pin: Z_STEP
dir_pin: !Z_DIR
enable_pin: !Z_EN
rotation_distance: 32
gear_ratio: 64:16
microsteps: 32
endstop_pin:  probe:z_virtual_endstop
position_max: 165
position_min: -5
homing_speed: 8
second_homing_speed: 3
homing_retract_dist: 3

[tmc2209 stepper_z]
uart_pin: Z_UART
interpolate: true
run_current: 0.8
sense_resistor: 0.110

##	Z1 Stepper - Rear Left 
[stepper_z1]
step_pin: Z1_STEP
dir_pin: Z1_DIR
enable_pin: !Z1_EN
rotation_distance: 32
gear_ratio: 64:16
microsteps: 32

[tmc2209 stepper_z1]
uart_pin: Z1_UART
interpolate: true
run_current: 0.8
sense_resistor: 0.110

##	Z2 Stepper - Rear Right 
[stepper_z2]
step_pin: Z2_STEP
dir_pin: !Z2_DIR
enable_pin: !Z2_EN
rotation_distance: 32
gear_ratio: 64:16
microsteps: 32

[tmc2209 stepper_z2]
uart_pin: Z2_UART
interpolate: true
run_current: 0.8
sense_resistor: 0.110

##	Z3 Stepper - Front Right 
[stepper_z3]
step_pin: Z3_STEP
dir_pin: Z3_DIR
enable_pin: !Z3_EN
rotation_distance: 32
gear_ratio: 64:16
microsteps: 32

[tmc2209 stepper_z3]
uart_pin: Z3_UART
interpolate: true
run_current: 0.8
sense_resistor: 0.110

########
# ADXL #
########

# [adxl345]
# cs_pin: thb:ADXL_CS
# spi_software_sclk_pin: thb:ADXL_SCLK
# spi_software_mosi_pin: thb:ADXL_MOSI
# spi_software_miso_pin: thb:ADXL_MISO
# axes_map: x,y,z

# [resonance_tester]
# accel_chip: adxl345
# accel_per_hz: 150
# probe_points:
#      87,90,20
# max_freq: 150
# sweeping_period: 0

############
# Extruder #
############

[extruder]
step_pin: thb:E_STEP
dir_pin: !thb:E_DIR
enable_pin: !thb:E_EN
microsteps: 16
nozzle_diameter: 0.400
filament_diameter: 1.750
heater_pin: thb:HE_HEATER
#sensor_type: Generic 3950
######################
#	Uncomment for NH36 #
######################
#pullup_resistor: 2200
sensor_pin: thb:HE_TEMP
control: pid
pid_Kp: 21.527
pid_Ki: 1.063
pid_Kd: 108.982
min_temp: 0
max_temp: 300
microsteps: 16
full_steps_per_rotation: 200	# 400 for 0.9 degree
nozzle_diameter: 0.400
filament_diameter: 1.75
pressure_advance: 0.05
pressure_advance_smooth_time: 0.040 # this can be calibrated later
##--------------------------------------------------------------------

## Uncomment for G2 Extruder 
#rotation_distance: 47.088 
#gear_ratio: 9:1

## Uncomment for BMG Extruder 
#rotation_distance: 22.6789511   #Bondtech 5mm Drive Gears
#gear_ratio: 50:10               #BMG Gear Ratio
##--------------------------------------------------------------------

##	E0 on Motor7
##	Make sure to update below for your relevant driver (2208 or 2209)
[tmc2209 extruder]
uart_pin: thb:E_UART
run_current: 0.650

##############
# Bed Heater #
##############

[heater_bed]
##	SSR Pin - HE1
heater_pin: BED_HEATER
sensor_type:Generic 3950
sensor_pin: BED_TEMP
max_power: 1
min_temp: 0
max_temp: 120
control: pid
pid_kp: 58.437
pid_ki: 2.347
pid_kd: 363.769

###########################
#	Uncomment for Leviathan #
###########################
#pullup_resistor: 2200


################
# PROBE CONFIG #
################

# Biqu MicroProbe #
#[include microprobe.cfg]

# Klicky #
#[include klicky.cfg]

# Beacon #
#[include beacon.cfg]

# Cartographer #
#[include carto.cfg]

# Boop #
#[include boop.cfg]

# E3D PZ PROBE #
#[include pzprobe.cfg]


###############
# Fan Control #
###############
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

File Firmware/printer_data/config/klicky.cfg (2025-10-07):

#############
# 	Probe
#############
[probe]
pin: ^thb:PROBE 
x_offset: 0
y_offset: 27.5
speed: 20
lift_speed:5
#z_offset: 5  # Will be overridden when you do a PROBE_CALIBRATE
samples: 2
samples_tolerance: 0.05
samples_tolerance_retries: 3

[bed_mesh]
speed: 120
horizontal_move_z: 10
mesh_min: 13,27.5
mesh_max: 160,140
probe_count: 5,5
algorithm: bicubic
fade_start: 1.0
fade_end: 10
mesh_pps: 2,2

######################
# Klicky Variables
######################

# This macro is based of the default klicky macros, but has been modified specifically for Micron, 
#you "SHOULDNT" need to adjust anything for it to work if
# you mounted the dock where it goes on the B drive correctly

[gcode_macro _User_Variables]
variable_verbose:             True    # Enable verbose output
variable_debug:              False    # Enable Debug output
variable_travel_speed:         200    # how fast all other travel moves will be performed when running these macros
variable_move_accel:          1000    # how fast should the toolhead accelerate when moving
variable_dock_speed:            50    # how fast should the toolhead move when docking the probe for the final movement
variable_release_speed:         75    # how fast should the toolhead move to release the hold of the magnets after docking
variable_z_drop_speed:          20    # how fast the z will lower when moving to the z location to clear the probe

variable_safe_z:         	    25    # Minimum Z for attach/dock and homing functions
# if true it will move the bed away from the nozzle when Z is not homed
variable_enable_z_hop:        True    # set this to false for beds that fall significantly under gravity (almost to Z max)

# if a separate Z endstop switch is in
# use, specify the coordinates of the switch here (Voron).
# Set to 0 to have the probe move to center of bed
variable_z_endstop_x:         0
variable_z_endstop_y:         0

#Check the printer specific documentation on klipper Dock/Undock configuration, these are dummy values
#dock location
variable_docklocation_z:      -128    # Z dock position (-128 for a gantry/frame mount)

#The following variables are used if the dock is deployed and retracted via a servo motor
variable_enable_dock_servo:  False    # Set to true if your klicky dock is servo-controlled
variable_servo_name:        'NAME'    # The name of the dock servo defined in printer.cfg under [servo]
variable_servo_deploy:          10    # This EXAMPLE is the value used to deploy the servo fully
variable_servo_retract:         11    # This EXAMPLE is the value used to retract the servo fully (initial_angle in [servo] config)
variable_servo_delay:          250    # This is a delay to wait the servo to reach the requested position, be carefull with high values

#Dock move, final toolhead movement to release the probe on the dock
#it's a relative move
Variable_dockmove_x:            50
Variable_dockmove_y:             0
Variable_dockmove_z:             0

Variable_docklocation_x:         24
Variable_docklocation_y:         190

#Attach move. final toolhead movement to attach the probe on the mount
#it's a relative move
Variable_attachmove_x:           0
Variable_attachmove_y:         50
Variable_attachmove_z:           0

#Umbilical to help untangle the umbilical in difficult situations
variable_umbilical:          True     # should we untangle the umbilical
variable_umbilical_x:           24    # X umbilical position
variable_umbilical_y:           140    # Y umbilical position

# location to park the toolhead
variable_park_toolhead:      True    # Enable toolhead parking
variable_parkposition_z:        30    # -128 excludes Z - Park only on X-Y

variable_version:                1    # Helps users to update the necessary variables, do not update if the variables above are not updated

#Below this remark, you normally do not need to configure
#Attach move2
Variable_attachmove2_x:          0    # intermediate toolhead movement to attach
Variable_attachmove2_y:          0    # the probe on the dock
Variable_attachmove2_z:          0    # (can be negative)

variable_home_backoff_x:        100    # how many mm to move away from the X endstop after homing X
                                      # this is useful for the voron v0 to enable the toolhead to move out of the way to allow an unstricted Y homing
variable_home_backoff_y:        10    # how many mm to move away from the Y endstop after homing Y

variable_override_homing:       ''    # configures what axis to home first
                                      #  '' = default klicky behavior (tries to avoid the hitting the dock)
                                      # 'X' = forces X to home first
                                      # 'Y' = forces Y to home first
                                      
variable_dock_on_zhome:       True    # docks the probe on Z Homing if not necessary (avoids hitting the bed on some printers       

variable_bypass_probe_docking:        False                               

# Do not modify below
gcode:
    {% set Mx = printer['configfile'].config["stepper_x"]["position_max"]|float %}
    {% set My = printer['configfile'].config["stepper_y"]["position_max"]|float %}
    {% set Ox = printer['configfile'].config["probe"]["x_offset"]|float %}
    {% set Oy = printer['configfile'].config["probe"]["y_offset"]|float %}
    {% set Oz = printer['configfile'].config["probe"]["z_offset"]|float %}

    # If x, y coordinates are set for z endstop, assign them
    {% if z_endstop_x != 0 or z_endstop_y != 0 %}
        SET_GCODE_VARIABLE MACRO=_Probe_Variables VARIABLE=z_endstop_x VALUE={ z_endstop_x }
        SET_GCODE_VARIABLE MACRO=_Probe_Variables VARIABLE=z_endstop_y VALUE={ z_endstop_y }

    # if no x, y coordinates for z endstop, assume probe is endstop and move toolhead to center of bed
    {% else %}
        SET_GCODE_VARIABLE MACRO=_Probe_Variables VARIABLE=z_endstop_x VALUE={ (Mx * 0.5) - Ox }
        SET_GCODE_VARIABLE MACRO=_Probe_Variables VARIABLE=z_endstop_y VALUE={ (My * 0.5) - Oy }
    {% endif %}


##################
# Klicky Macros 
##################

# This macro was provided by discord user Garrettwp to whom i give my thanks for sharing it with me.
# I have tweaked it a lot.
# They are based on the great Annex magprobe dockable probe macros "#Originally developed by Mental,
# modified for better use on K-series printers by RyanG and Trails", kudos to them.
# That macro as since evolved into a klipper plugin that currently is pending inclusion in klipper,
# more information here, https://github.com/Annex-Engineering/Quickdraw_Probe/tree/main/Klipper_Macros
# User richardjm revised the macro variables and added some functions
# User sporkus added led status notifications
# Thanks to all who helped,
# by standing on the shoulders of giants, lets see if we can see further
#
# the current home for this version is https://github.com/jlas1/Klicky-Probe

[respond]

[gcode_macro _Probe_Variables]
variable_probe_attached:            False
variable_probe_state:               False
variable_probe_lock:                False
variable_probe_z_homed:             False
variable_z_endstop_x:               0
variable_z_endstop_y:               0
gcode:


#checks if the variable definitions are up to date
[gcode_macro _klicky_check_variables_version]
gcode:
    {% set version = printer["gcode_macro _User_Variables"].version|default(0) %}

    {% if version != 1 %}
        { action_raise_error("Please update your klicky variables, there are some functionality changes") }
    {% endif %}

[gcode_macro _KlickyDebug]
gcode:
    {% set message  = params.MSG %}
    {% set debug = printer["gcode_macro _User_Variables"].debug|default(False) %}

    {% if debug %}
        { action_respond_info(message) }
    {% endif %}


[gcode_macro _exit_point]
gcode:
    {% set function  = 'pre_' ~ params.FUNCTION %}
    {% set move  = params.MOVE|default(0) %}
    {% set speed = printer["gcode_macro _User_Variables"].travel_speed %}

    # mandatory to save the new safe position
    M400
    SET_VELOCITY_LIMIT ACCEL={printer.configfile.settings.printer.max_accel}
    RESTORE_GCODE_STATE NAME={function} MOVE={move} MOVE_SPEED={speed}


[gcode_macro _entry_point]
gcode:
    {% set function  = 'pre_' ~ params.FUNCTION %}
    {% set move_accel = printer["gcode_macro _User_Variables"].move_accel|default(1000) %}
    # mandatory to save the new safe position
    M400
    SAVE_GCODE_STATE NAME={function}
    # removes the Z offset for better bed based docking
    SET_GCODE_OFFSET Z=0
    # all the macros initially assume absolute positioning
    G90
    # set a safe(sane) Acceleration
    SET_VELOCITY_LIMIT ACCEL={move_accel}

[gcode_macro _Homing_Variables]
gcode:
    {% set reset  = params.RESET|default(0) %}
    {% if reset %}
        SET_GCODE_VARIABLE MACRO=_Probe_Variables VARIABLE=probe_lock VALUE={ False }
    {% endif %}
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

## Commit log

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2021-05-24 fixed z tensioner brackets and added corner bracket to mount bed extrusions
    [[a]_1515_Corner_Bracket_x4.stl, z_tensioner_bracket_a_x2.stl, z_tensioner_bracket_b_x2.stl]
2021-05-24 updated to fixed XY Joints with fixed belt path
    [xy_joint_left_lower.stl, xy_joint_left_upper.stl, xy_joint_right_lower.stl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]
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2021-06-08 updated CAD and fixed issues with XY joints
    [MGN9-rail_installation_guide_center_x2.stl, xy_joint_left_lower.stl, xy_joint_left_upper.stl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]
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2021-08-06 Updated skirt to re-include chamfers, and added more tolerance around the inlet.
    [new_rear_micron_skirt_and_alt_z_motor_mounts.SLDASM, new_rear_micron_skirt_and_alt_z_motor_mounts.STEP, rear_micron_skirt_and_inlet_8_5_21.STEP]
2021-08-07 Added mounting for octopus/spider/pi. Revised rear skirt-- should hold in the inlet. Added mounting for uhp-200. Corrected z_drive_main_b STL. Corrected [a]_z_motor_mount_* STLs-- should now use the 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
    [new_rear_micron_skirt_and_alt_z_motor_mounts.SLDASM, new_rear_micron_skirt_and_alt_z_motor_mounts.STEP, octopus_spider_and_pi_mount.SLDPRT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]
2021-08-08 Added trim pieces. Added mounting for UHP-200 PSW. Modified skirt to accept trim pieces Modified board mounts to also accept fan, and enhance clearances with skirts.
    [[a]_front_rear_skirt_trim_x2.stl, [a]_side_skirt_trim_x2.stl, front_rear_bottom_trim.SLDPRT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]
2021-08-08 Redundant and old-- removing to prevent confusion.
    [new_rear_micron_skirt_and_alt_z_motor_mounts.SLDASM, new_rear_micron_skirt_and_alt_z_motor_mounts.STEP]
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2021-08-13 fixed orientation and added mirror
    [Nema 17 Z Motor mount mirror.stl, Nema 17 Z Motor mount.stl]
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2021-08-22 Add files via upload
    Replaced correct stl orientation
    [AntiRotationCornerBracket.stl]
2021-08-23 Modified for clearances, shorter motor mount. Added "new_front_rear_skirt.sldprt", which has a front and rear configuration, instead of having two separate parts that share mostly everything.
    [new_front_rear_skirt.SLDPRT, new_front_skirt.SLDPRT, new_front_skirt.STEP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]
2021-08-23 removed redundant parts replaced by new_front_rear_slort.sldprt
    [new_front_skirt.SLDPRT, new_rear_skirt.SLDPRT]
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2021-08-23 Added motor cover that has more clearance for z motor spindle
    [motor_cover.STEP]
2021-08-23 Revised motor cover and added missing sldprt file.
    [motor_cover.SLDPRT, motor_cover.STEP]
2021-08-23 Fixed voron logo and made surfaces more planar and pretty.
    [motor_cover.SLDPRT, motor_cover.STEP]
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2021-08-23 Fixed tolerancing error on motor cover, and updated sldprt for front/rear skirt.
    [motor_cover.SLDPRT, motor_cover.STEP, new_front_rear_skirt.SLDPRT]
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2021-08-24 Added a bit more clearance for the motor spindle.
    [motor_cover.SLDPRT, motor_cover.STEP]
2021-08-24 Removed the older "new" motor_cover, and replaced with two variants at two different heights. Updated the sldprt to make changing heights a matter of a single dim change.
    [2_5mm_tall_motor_cover.STEP, 5mm_tall_motor_cover.STEP, motor_cover.SLDPRT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]
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2021-09-04 Added some more mounting holes for front skirt, reduced some "meat" that was causing some potential printability issues, other minor changes.
    [new_front_rear_skirt.SLDPRT, new_front_skirt.STEP, new_rear_skirt.STEP]
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2021-09-07 Heatset hole was wrong diameter, and set the distance more precisely.
    [Z Drive.SLDPRT, Z Drive.STEP]
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2021-09-07 Modified XY joints: Add clearance for bearings
    [xy_joint_left_lower.stl, xy_joint_left_lower_pinned.stl, xy_joint_right_lower.stl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]
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2021-09-08 Fix issue#7: Replace M3x6 with M3x8 SHCSs
    [[a]_z_drive_baseplate_a_x2.stl, [a]_z_drive_baseplate_b_x2.stl]
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2021-09-08 Fixed screw head collision
    [side_skirt_x2.stl]
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2021-09-09 Fixed hole-position error for hinge. Fixed hole-diameter error for lock-arm. Included heatsets, M3s and M2s for fastening everything together.
    [PSU_clip_dc_side.STEP, PSU_clip_dc_side.STL, hinge.SLDPRT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]
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2021-09-13 Added verified-working shorter endstop for use when the deck panel is flush with the top of the extrusions. Added variants for 8mm/9mm OD sleeve bearings.
    [z_nozzle_endstop_body_short.SLDPRT, z_nozzle_endstop_body_short_8mmOD_bearing.STEP, z_nozzle_endstop_body_short_9mmOD_bearing.STEP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]
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2021-09-13 Added assembly STEP for short endstop.
    [z_nozzle_endstop_short_pcb.STEP]
2021-09-13 Fixed incorrect heat-set hole sizes (previously 5mm, now the correct 4.7mm), and regenerated files.
    [PSU_clip_ac_side.SLDPRT, PSU_clip_ac_side.STEP, PSU_clip_dc_side.SLDPRT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]
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2021-09-15 Updated endstop with new BoM stuff. Since that allowed a closer clearance with the bed, horizontally, moved to make it closer to the bed as well. Added "Angerey" eyes.
    [z_nozzle_endstop_short_pcb.SLDASM, z_nozzle_endstop_short_pcb.STEP]
2021-09-17 Redid the motor-cover to have better engagement with the mating surface. Changed the "high clearance" version of the motor-cover to have a 6mm gap, and re-outputted 'em. Redid the CAD for the short e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
    [2_5mm_tall_motor_cover.STEP, 5mm_tall_motor_cover.STEP, [a]_z_endstop_housing_x1.stl]
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2021-09-20 added missing z belt covers
    [[a]_z_belt_cover_mirror_x2.stl, [a]_z_belt_cover_x2.stl]
2021-09-20 New Cad , updated z tensioner to make belt a little easier to route, fixed z chain anchors to be printable
    [[a]_z_anchor_frame_x1.stl, [a]_z_tensioner_x4_6mm.stl, frame_anchor_x1.stl]
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2021-09-27 Modified side skirt to have correct heatset-hole size. Also provided access to z-drive mounting holes through skirt and trim.
    [[a]_side_skirt_trim_x2.stl, side_skirt.SLDPRT, side_skirt.STEP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]
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2021-09-27 Normalized skirt STL naming. Changed front/rear skirts to have correct hole-size for heat-sets. Improved clearance/access for skirt mounting screws. Added additional clearance for motor tensioning.
    [[a]_front_rear_skirt_trim_x2.stl, front_rear_bottom_trim.SLDPRT, front_rear_bottom_trim.STEP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]
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2021-09-30 Added versions with clearance, and for those new "with clearance" versions, made it so you don't need to add shims on the sides.
    [z_tensioner_heatset.SLDPRT, z_tensioner_heatset_pinned_with_clearance_and_no_shims.STEP, z_tensioner_heatset_with_clearance_and_no_shims.STEP]
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2021-10-14 Removed old CAD files for motor mount. Replaced with new files. Added NEMA17 option for mounting motors. Added STLs for same.
    [Mirroralt_z_motor_mount.SLDPRT, Mirroralt_z_motor_mount.STEP, [a]_z_motor_mount_a_x2.stl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]
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2021-10-15 Oops. forgot to make the holes pass-through for M3. Fixed. Motor mount holes now pass-through M3 again.
    [longboi_z_motor_mount.SLDPRT, longboi_z_motor_mount_nema14.STEP, longboi_z_motor_mount_nema17.STEP]
2021-10-15 fixed right lower xy joint
    [xy_joint_right_lower.stl]
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2021-10-20 Shorten [a]_probe_dock_x1 for more print volume
    [[a]_probe_dock_x1.stl]
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2021-10-23 Added split side skirt. FIxed incorrect location and naming for two_piece side trim parts.
    [[a]_side_skirt_trim_two_piece_a_x2.stl, [a]_side_skirt_trim_two_piece_b_x2.stl, side_skirt.SLDPRT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]
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2021-10-23 Fixed to not be keyed.
    [new_front_skirt_two_piece_a.STEP, new_front_skirt_two_piece_b.STEP, new_rear_skirt_two_piece_a.STEP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]
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2021-10-23 Fixed printing orientation for the motor covers. Renamed the 8mm variant appropriately.
    [[a]_2_5mm_gap_1mm_thick_motor_cover_x4.STL, [a]_6mm_gap_1mm_thick_motor_cover_x4.STL, [a]_8mm__gap_1mm_thick_motor_cover.STL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]
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2021-10-24 Added missing parts from Mini-AB
    [Guidler_DD_x1.stl, Latch_DD_x1.stl, Latch_Shuttle_DD_x1.stl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]
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2021-11-23 moved files around, fixed z rail alignment measurement, updated rail alignment stl with correct measurements
    [2_5mm__gap_1mm_thick_motor_cover.STEP, 60mm_fan_assembly.SLDASM, 60mm_fan_assembly.STEP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]
2021-11-29 Fixed panel sizes and added new DXFs
    [door_panel_x1.dxf, side_panel_x2.dxf, top_panel_x1.dxf]
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2021-12-29 fixed slicing issue with Z tensioners
    [z_tensioner_bracket_a_x2.stl, z_tensioner_bracket_b_x2.stl]
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2022-01-06 added new wide z chain, and fixed xy joints, updated cad, cable gland a drive
    [[a]_z_anchor_frame_x1.stl, [a]_z_anchor_gantry_x1.stl, [a]_z_link_x18.stl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]
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2022-02-01 Modified stacked electronics mounting to (mostly) accomodate spider. ... still need to add a fixture between spider_PSU-clip_ac_side and the spider, but should be mostly functional otherwise.
    Improved clearances between pi and bottom panel.
    [MirrorPSU_clip_dc_side.SLDPRT, PSU_clip_ac_side.SLDPRT, PSU_clip_ac_side.STEP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]
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2022-02-11 fix panel clips
    panel clip geometry had hollow voids thast made them slice weird. fixed, replaced stls, and added cad
    [CenterPanelClip.step, center_panel_clip_x15.stl, corner_panel_clip_x16.stl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]
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2022-02-14 get rid of problematic space in directory naming
    fixed mods readme to match new path
    [[a]_tensioner_a_pinned.stl, [a]_tensioner_b_pinned.stl, [a]_z_tensioner_x4_6mm_pinned.stl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]
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2022-03-27 Updated to correctly bed-mesh (and not crash), and improvements to xy sensorless homing.
    [klicky-z-calibration.cfg, printer.cfg]
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2022-04-03 Updated with some bugfixes, improvements.
    [beethovans_fifth.cfg, klicky-variables.cfg, klicky-z-calibration.cfg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]
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2022-04-22 Most recent updates to the printer config. Bugfixes too!
    [klicky-z-calibration.cfg, printer.cfg]
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2022-06-03 updated z anchor frame mount to include the newer version as well as fixed nema 14 z motor B mount , had issues in the slicer that needed a reexport
    [[a]_z_anchor_frame_x1.stl]
2022-06-05 replaced z motor cover with easier to print covers
    [[a]_8mm__gap_1mm_thick_motor_cover_x4.STL, [a]_z_motor_cover_x4.STL]
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2022-06-28 updated orientation of A drive and B drive to correct orientation for printing
    [[a]_z_nema_14_motor_mount_a_x2.stl, [a]_z_nema_14_motor_mount_b_x2.stl]
2022-06-29 fixed new z motor mounts to include built in support
    [[a]_z_nema_14_motor_mount_a_x2.stl, [a]_z_nema_14_motor_mount_b_x2.stl]
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2022-09-08 removed no longer needed micron160 gantry specific parts, and added prusa mini bed wire cover
    [PrusaMiniBed_WireCover_Micron.stl, PrusaMiniBed_WireCover_Micron_bottom_heatset.stl, a_drive_lower_160.stl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]
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2022-10-06 fixed skirts in cad assembly for Micron120 , added Micron+ skirt files for MellowTFT display
    [FanMount_A.stl, FanMount_B.stl, [a]_frontSkirt_mesh_x2.stl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]
2022-10-18 fix 17 z motor mounts
    [[a]_z_nema_17_motor_mount_a_x2.stl, [a]_z_nema_17_motor_mount_b_x2.stl]
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2022-10-24 added MicronPlus electronics mounts, new front and rear skirts to fix nema17 motor mount issues, as well as new nema 17 motor mounts , new micronPlus bottom panel stl as well as DXF
    [BottomPanel.dxf, BottomPanel.stl, Octopus_bracket_set.stl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]
2022-11-02 micron+ skirt updates and nema14 motor fixes
    [FanMount_A.stl, FanMount_B.stl, SlottedSkirtControllerFan.step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]
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2022-11-15 fixed XY joint upper to easier fit m3x8s, fixed nema17 mounts to fit m3x8s to extrusions better, added 3 slot bed wagos to my mods folder
    [[a]_z_nema_17_motor_mount_a_x2.stl, [a]_z_nema_17_motor_mount_b_x2.stl, bw_micron_3.stl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]
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2022-11-21 fixed orientation and added 120 R1 Beta skirts
    [[a]_fan_grill_mirror_x2.stl, [a]_fan_grill_support_x2.stl, [a]_fan_grill_x2.stl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]
2022-11-25 Uploaded new complete cad assmebly to bring micron+ into mainline micron and no longer a Mod , added folders for 120 vs 180 sized parts
    [BLACK_DeckPanel_x1.dxf, BLACK_RearPanel_x1.dxf, BottomPanel.dxf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]
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2022-11-26 added missing screws to cad fixed door hinge piece , closed up hole a bit for better bit of m3 screw
    [hinge_door_x2.stl]
2022-11-26 fixed minor misalignment in XY joints
    [xy_joint_left_lower.stl, xy_joint_right_lower.stl]
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2022-12-18 Delete Mods/clee/Micron+/STLs directory
    no longer needed
    [ExhaustCover.stl]
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2023-03-03 updated CAD assembly and fixed naming of some of the STLs
    [1515_Din_rail_mount.stl, 1515_Din_rail_mount_x4.stl, 180_front_skirt.stl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]
2023-03-18 new gantry , fixed minor alignment issues
    [[a]_a_tensioner_x1.stl, [a]_b_tensioner_x1.stl, [a]_tensioner_a.stl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]
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2023-03-24 updated XY joints belt alignment issues, added alignment tabs on extra a drive upper frame pieces
    fixes issue https://github.com/PrintersForAnts/Micron/issues/89
    [a_drive_upper_m12_x1.stl, a_drive_upper_pg7_x1.stl, a_drive_upper_pg9_x1.stl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]
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2023-03-26 updated pin mod for newest gantry fix
    [[a]_tensioner_a_pinned.stl, [a]_tensioner_b_pinned.stl, [a]_tensioner_pinned_x2.stl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]
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2023-03-27 fixed a drive uppers and orientation on b drive lower pinned
    [a_drive_frame_upper_pinned.stl, a_drive_frame_upper_pinned_M12.stl, a_drive_frame_upper_pinned_PG7.stl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]
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2023-05-01 Various updates
    fixed the alignment of the Z drive gt2 16pulley (moved it over 1.2mm) and adjusted printed spacers to match (3.4mm change to 4.6mm, and 2.2mm change to 1mm)
    fixed the screw holes in the XY Joints Lower Left and Right
    added updated CAD assembly in both .F3D and .Step
    [[a]_1mm_z_drive_spacer_x4.stl, [a]_2.2mm_z_drive_spacer_x4.stl, [a]_3.4mm_z_drive_spacer_x4.stl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]
2023-05-04 latest fix for XY joints to move bearings in and get belt aligned properly
    [xy_joint_left_lower.stl, xy_joint_left_upper.stl, xy_joint_right_lower.stl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]
2023-05-19 fixed probe mount to work with m3x16s better, added z drive spacers for different pulley setups
    [1.2mm_z_drive_spacer_x4.stl, 1mm_z_drive_spacer_x4.stl, 2.2mm_z_drive_spacer_x4.stl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]
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2023-06-05 fixed hole size for stepper mounting on lower A and B drive
    [a_drive_lower_x1.stl, b_drive_lower_x1.stl]
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2023-08-05 Fix for undersized hole on A Drive Frame Lower
    The hole for the double bearing stack on the Lower part of the A Drive Frame was undersized compared to other holes for the pin mod.
    Removed chamfer, pulled the hole from 1.40mm to 1.65mm to create the correct sized hole, then re-added the 0.4mm chamfer.
    STL & CAD updated, CAD also has A Drive Frame Upper bodies renamed to better reflect the various umbilical mount sizings.
    [a_drive_frame_lower_pinned.stl]
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2023-10-23 added missing bridgdd hole
    [[a]_g2_z_drive_mount_a_x2.stl, [a]_g2_z_drive_mount_b_x2.stl]
2023-10-26 fixed G2Z drive mount files that were getting hit by the m3 fhcs
    [[a]_g2_z_drive_mount_a_x2.stl, [a]_g2_z_drive_mount_b_x2.stl]
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2023-11-16 R1 beta rev3
    fixed bottom of AB drives to fit better on different Steppers
    adjusted keying features on AB Drives to fit better
    fixed keying features on XY joints
    fixed bearing/idler screw holes on right lower xy joint to 2.9mm from 3.4
    fixed orientation of front idler body
    [[a]_klicky_gantry_dock.stl, a_drive_lower.stl, a_drive_upper.stl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]
2023-11-17 fixed bearing screw holes sizes
    [a_drive_lower.stl, b_drive_lower.stl]
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2024-01-22 R1 gantry pieces updated
    Was messing with making belt different belt paths helping someone model teeth for a gantry and I noticed I messed up on the bearing stacks for the gantry on R1
    I made the pitch line diameter for the belt to follow 10.376mm it should be 10.752 ...Its supposed to be
    2*(R+.376)
    I did (2*R)+.376
    .376 is the value from the smooth side of the belt to the pitch line of the belt
    So this makes it so the belt in CAD that is wrapped around the bearing not exactly where it's supposed to be
    In the CAD the belt that is wrapped around the bearings has a radius of 4.812 and it SHOULD be the same as the bearing (5)
    5-4.812 = .188 and
    .188 X2 is that 2nd .376 I didn't add to belt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
    [Micron+_MIC6_Bed.step, idler_body_x2.stl, xy_joint_left_lower.stl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]
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2024-01-27 fixed bottom mounting hole on XY joints
    [xy_joint_left_lower.stl, xy_joint_right_lower.stl]
2024-02-01 fixed naming and orientation of the m2 nut adapters
    [120_m2_nut_adapter_x6.stl, 180_long_m2_nut_adapter_x6.stl, 180_short_m2_nut_adapter_x12.stl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]
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2024-02-05 added clearance for bigger 16t idler pulleys to XY joints
    [xy_joint_left_lower.stl, xy_joint_left_upper.stl, xy_joint_right_lower.stl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]
2024-02-07 fixed XY joints, renamed folder names
    [[a]_idler_carrier_x2.stl, [a]_idler_front_cap_x2.stl, [a]_klicky_gantry_dock.stl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]
2024-02-08 fixed xy pinned joints
    [xy_joint_left_lower.stl, xy_joint_left_upper.stl, xy_joint_right_lower.stl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]
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2024-02-22 new door parts uploaded and fixed some probe mounts
    [BIQU_micro_probe_mount_x1.stl, [a]_logo_x1.stl, [a]_x_endstop_sensorless_bumper_x1.stl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]
2024-02-24 updated holes in the hinges , screws were a bit loose
    [bottom_hinge_leaf_x1.stl, hinge_barrel_x2.stl, top_hinge_leaf_x1.3mf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]
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2024-03-13 few updates to BFI for R1
    - adjusted cover so it works in either orientation
    - added logo and logo insert for BFI front cover
    - corrected printing orientation to default parts to a 45deg rotation on the bed
    [[a]_front_cover_logo_x2.stl, [a]_front_cover_x2.stl, [a]_idler_carrier_x2.stl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]
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2024-03-18 update G2Z to fix belt path for corrected belt path for BZI
    [[a]_g2_z_drive_mount_a_x2.stl, [a]_g2_z_drive_mount_b_x2.stl, g2_z_spacer_plate_a_x2.stl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]
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2024-05-06 fixes multiple issues
    Fixes #115, #116, #117 , #118
    update cad assembly with all latest changes as well
    [[a]_klicky_gantry_dock.stl, [a]_klicky_gantry_probe_dock.stl, [a]_shaft_assembly_cover_a_x2.stl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]
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2024-05-07 Fix pull request
    Sorry i accidently uploaded the same thing two times.
    [1515 30mm Bed Fan Mount - body_left.step, 1515 30mm Bed Fan Mount - body_left.stl, 1515 30mm Bed Fan Mount - body_right.step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]
2024-05-07 Fixed print orientation in STL files
    I dont know how change this in STEP file sorry, but STL are oriented correctly.
    [1515 30mm Bed Fan Mount - body_left.step, 1515 30mm Bed Fan Mount - body_left.stl, 1515 30mm Bed Fan Mount - body_left_step.step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]
2024-05-07 updated klicky dock to include ziptie mounts on the back as well as fixed the height
    [[a]_klicky_gantry_dock.stl]
2024-05-14 updated the Z drives to fix issue #120
    extended the shafts slot to allow up to 60mm long shaft for the Z drives
    [[a]_foot_mount_a_x2.stl, [a]_foot_mount_b_x2.stl, [a]_nema_14_motor_mount_x4.stl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]
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2024-05-21 updated Z drives
    fixed issue #122
    fixed issue #124
    [[a]_foot_mount_a_x2.stl, [a]_foot_mount_b_x2.stl, [a]_nema_14_motor_mount_x4.stl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]
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2024-07-02 Fixed #126 Fixed #128
    added G2Z hula feet adapters
    R1Z hula feet adapters
    updated R1Z drives
    added skirts (side and front waveshare/btt display mount) cad files
    updated the main R1 cad assembly to the latest version
    [Micron_Hula_Feet.step, Micron_Hula_G2Z_Feet.step, [a]_foot_mount_a_x2.stl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]
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2024-07-24 added panel clips and fixed beacon probe mount , fixed z belt covers
    [[a]_bowden_tube_entry_inside_cover_x1.stl, [a]_logo_x1.stl, [a]_z_cover_main_body_a_x2.stl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]
2024-07-25 added twist lock panel clips for 3mm foam and panels, fixed orientation of rail stops and an umbilical mount
    [[a]_railstops_x12.stl, [a]_twist_lock.stl, [a]_umbilical_mount_PG9_3hole_x1.stl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]
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2024-07-28 fixed waveshare display accent pieces, uploaded latest cad assembly
    [[a]_waveshare_display_accent_a_x1.stl, [a]_waveshare_display_accent_b_x1.stl]
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2024-08-24 Added step files and corrected part orientations
    [1515 Bed Angle Bracket Notched.step, 1515 Bed Angle Bracket Notched.stl, 1515 Daygreen 5VDC Regulator Mount.step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]
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2024-09-03 added missing files , fixed naming issue
    [[a]_bowden_tube_entry_inside_cover_MMU_x1.stl, [a]_spool_holder_mount_x1_.stl, [a]_twist_lock_key_x47.stl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]
2024-09-06 cleaned up CAD and adjusted gantry files
    * cleaned up main cad assembly
    * posted link to fusion source assembly file to be downloaded
    * adjusted gantry files to no longer need built in printed shim, now there are shims on both sides of every bearing stack
    [[a]_front_cover_x2.stl, [a]_handle_mounting_cover_a_x2.stl, [a]_handle_mounting_cover_b_x2.stl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]
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2024-09-18 fixed counterbore bridging on the rear bowden entry files , updated cad assembly, removed all redundant files in the cad assembly
    [bowden_tube_entry_rear_cover_ECAS_MMU_x1.stl, bowden_tube_entry_rear_cover_ECAS_x1.stl, bowden_tube_entry_rear_cover_M10_MMU_x1.stl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]
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2024-10-18 fixed issues with fan grill and side skirt accents
    [[a]_fan_grill_x2.stl, [a]_side_skirt_a_accent_x2.stl, [a]_side_skirt_b_accent_x2.stl]
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2024-11-07 Revert "added 12mm no drop nuts for formbot kit and archetype BB klicky dock"
    This reverts commit c38844a607a66c36feb0da10ba75567cfcd2e76f.
    [KlickyPCBDock_ArchetypeBB.STEP, KlickyPCBDock_ArchetypeBB.STL, nodropnut double 12mm spacing.STEP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]
2024-11-07 Reapply "added 12mm no drop nuts for formbot kit and archetype BB klicky dock"
    This reverts commit ba13055ebba6fd9d81fa06e47def2f959a31c88d.
    [KlickyPCBDock_ArchetypeBB.STEP, KlickyPCBDock_ArchetypeBB.STL, nodropnut double 12mm spacing.STEP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]
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2025-01-20 fixed #143 , fixed #141, fixed #138 , fixed #137
    organized cad, fixed various issues
    #143 , #141, #138 , #137
    [[a]_bezel_x1.stl, [a]_fan_grill_x2.stl, [a]_waveshare_display_accent_a_x1.stl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]
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2025-03-03 Fixed #148, Fixed #149
    added parametric panel clips cad file
    fixed wrong hardware in front idlers,
    fixed miss aligned heatsets in Z drives
    added m5 shims/washers to z drive shaft assembly
    simplified the anthead cad to be a default option if you want the rest of the cad its in the https://www.github.com/PrintersForAnts/AntHead repo
    [1515_ParametricPanelClips.f3z, Live Idlers v3.f3d, [a]_z_live_idler_pulley_x4.stl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]
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2025-04-16 fixed and renamed the bed fan wago mount
    [wago mount 412 with bed fans x1.stl, wago_mount_413_x1.stl]
2025-04-17 deleted old empty folders and fixed #159
    [[a]_z_belt_bed_fan_mount_a_x1.stl, [a]_z_belt_bed_fan_mount_b_x1.stl]
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2025-04-21 fixed blank keystone insert and updated rear skirt (adamstech inlet) to give more room for wiring
    [[a]_keystone_blank_insert_x2.stl, rear_skirt_inlet_adamstech_x1.stl]
2025-04-25 fixed minor chamfer that was missing
    [a_drive_lower_pinned_x1.stl, main_housing.stl]
2025-05-28 added fan grills to the bed fans and uploaded the latest cad assembly (RC4) and fixed #161
    [z_belt_fan_cover_a.stl, z_belt_fan_cover_b_.stl]
2025-05-29 updated bed fans to have hexagon grill inserts fixed #163
    [[a]_bed_fan_grill_x2.stl, z_belt_fan_cover_a.stl, z_belt_fan_cover_b_.stl]
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2025-07-08 fixed #145 , fixed #166 , fixed #180 , fixed #181
    also added pinned z idlers to match the rest of the printer having pinned versions as well
    [[a]_z_belt_bed_fan_mount_a_x1.stl, [a]_z_belt_bed_fan_mount_b_x1.stl, [a]_z_idler_bearing_stack_pinned_x4.stl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]
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2025-08-02 Update x_carriage_mgn9h_x1.stl , fixed issue with anthead fans hitting the carriage as well as the offset between the probe mounts and the face of the carriage
    offset was 4.57mm it should be 5mm
    [x_carriage_mgn9h_x1.stl]
2025-08-14 config updates (#188)
    * config updates
    adjusted m8pv2 cfg motor aliases to use _UART instead of _CS.
    printer.cfg updated to move ADXL pins to thb, and add thb mcu temperature sensor.
    * v1-1 and additional v2 corrections
    [BTTMantaM8P_v1-1.cfg, BTTMantaM8P_v2.cfg, printer.cfg]
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2025-09-09 replaced the screwed on panel clips with the correct STLs
    [center_panel_clip_x15.stl, corner_clip_x16.stl, screwed_center_panel_clip_x15.stl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]
2025-09-29 Update klicky.cfg
    Fixed missing toolhead board alias on pin name
    [klicky.cfg]
2025-10-07 fixed #190 , fixed #184 , fixed #146
    updated latest cad assembly
    added some various files to the mods folders
    [1515_ParametricPanelClips.f3z, CNC_Carriage.step, MicronLogo_armor_chest_plate.stl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]
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2026-09-18 fixed minor issue with panel clips
    Old stls were no effected , cad had the issue now both stls and cad match
    Also adjusted panelclip to work with square cut panels now as well
    [1515_ParametricPanelClips.f3z, screwed_center_panel_clip_x15.stl, screwed_corner_panel_clip_x16.stl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]
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2026-09-24 new WIP manual update
    fixed bowden tube holder printing orientation
    added rear panel umbilical mod
    [Rear_Panel_Umbilcal.step, bowden_tube_holder_x2.stl]
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
